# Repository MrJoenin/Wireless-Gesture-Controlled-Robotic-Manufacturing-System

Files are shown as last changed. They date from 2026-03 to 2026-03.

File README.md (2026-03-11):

# 🦾 Wireless Gesture-Controlled Robotic Manufacturing System

A 6-DOF robotic arm controlled wirelessly in real-time using hand gestures captured by an MPU6050 IMU and transmitted via RF communication.

---

## 📸 Demo
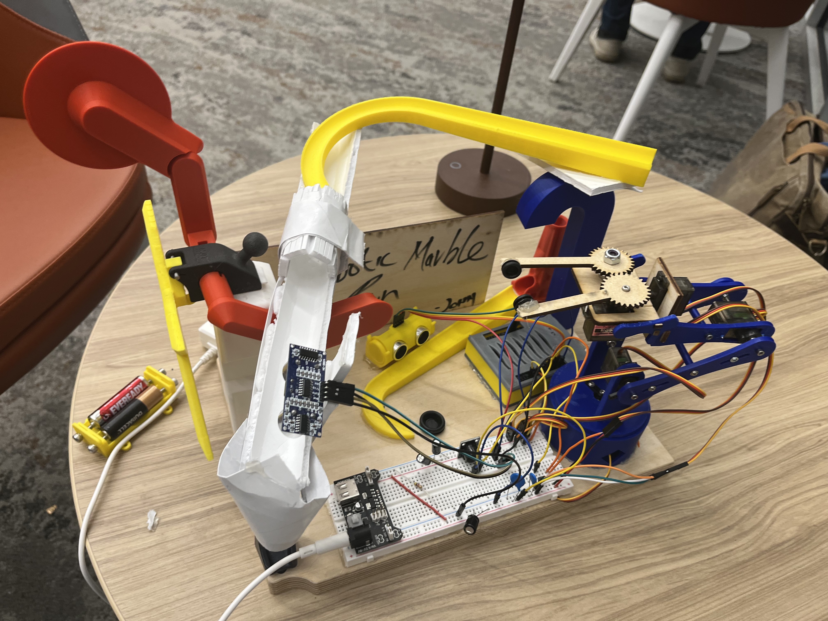
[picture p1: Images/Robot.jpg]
Wireless Gesture-Controlled Robotic Arm


🎥 [Watch Full Demo Video](https://drive.google.com/drive/folders/1Te0tW6EEjBbD6eXdm4avNDmqE-6lIaKK?usp=drive_link)

---

## 🔍 Overview

This system allows an operator to control a robotic arm simply by moving their hand. An **MPU6050 gyroscope/accelerometer** captures wrist orientation and transmits motion data wirelessly via **RF modules** to a receiver Arduino that drives **6 servo motors** — one per joint. An **ultrasonic sensor** detects nearby objects and triggers a **buzzer** as a proximity alert.

This project was built as a group capstone for **ECET-230-001**, covering embedded systems, wireless communication, PCB design, and mechanical design end-to-end.

---

## ✨ Features

- Real-time wireless gesture control via MPU6050 IMU (pitch, roll, yaw)
- 6 degrees of freedom — base, shoulder, elbow, wrist pitch, wrist roll, gripper
- RF 433MHz communication between handheld controller and arm
- Ultrasonic proximity detection with piezo buzzer audio alert
- LCD display for live system status feedback
- Custom PCB designed in KiCad
- 3D printed mechanical structure (PLA+ / PETG)
- Full project documentation: schematics, logs, test plans, CAD files

---

## ⚙️ Hardware Components

| Component | Quantity | Purpose |
|---|---|---|
| Arduino Uno | 2 | Transmitter & Receiver microcontrollers |
| MPU6050 IMU | 1 | Captures hand orientation (I2C) |
| RF Transmitter + Receiver (433MHz) | 1 pair | Wireless data link |
| Servo Motors | 6 | Drives each joint of the arm |
| Ultrasonic Sensor (HC-SR04) | 2 | Object/proximity detection |
| Piezo Buzzer | 1 | Audio proximity alert |
| LCD Display (I2C) | 1 | Live system status |
| Push Buttons | 5 | Manual input controls |
| LEDs (Red & Green) | 2 | Status indicators |
| 9V Battery + Battery Pack | 1 | Portable power supply |
| Custom PCB (KiCad) | 1 | Clean circuit integration |

**Estimated Total Cost: Under $150**

---

## 🧠 How It Works

```
[ Hand Movement ]
       ↓
[ MPU6050 reads pitch / roll / yaw ]
       ↓
[ Transmitter Arduino encodes data + sends via RF ]
       ↓
[ Receiver Arduino decodes signal ]
       ↓
[ 6 Servo motors move to matching joint angles ]
       ↓
[ Ultrasonic sensor monitors proximity → Buzzer alert ]
```

---

## 🛠️ Tools & Technologies

| Category | Tools |
|---|---|
| Programming | Arduino IDE (C/C++) |
| Mechanical Design | SolidWorks / Fusion 360 |
| PCB Design | KiCad |
| Manufacturing | 3D Printing (PLA+ / PETG), Laser Cutting |
| Version Control | GitHub |
| Libraries | `Wire.h`, `MPU6050.h`, `VirtualWire`, `Servo.h`, `LiquidCrystal_I2C.h` |

---

## 📁 Repository Structure

```
Wireless-Gesture-Controlled-Robotic-Manufacturing-System/
├── Software/           # Arduino .ino source files (transmitter & receiver)
├── Design/             # System architecture, block diagrams, circuit schematics
├── PCB Files/          # KiCad PCB design files
├── Robot 3D Model/     # SolidWorks / Fusion 360 CAD files
├── Logs/               # Weekly progress logs
├── Tasks/              # Task tracking and completion status
├── Definitions/        # Official project scope and requirements
├── Proof of Concept.md # Early validation and feasibility notes
├── Testing Document.md # Test cases, results, and validation
├── LICENSE
└── README.md
```

---

## 🚀 Getting Started

### Prerequisites
- Arduino IDE installed
- Required libraries (install via Library Manager):
  - `MPU6050` by Electronic Cats
  - `VirtualWire` or `RadioHead` for RF
  - `LiquidCrystal_I2C` for LCD
  - `Servo` (built-in)

### Upload Steps

1. Clone this repo:
   ```bash
   git clone https://github.com/MrJoenin/Wireless-Gesture-Controlled-Robotic-Manufacturing-System.git
   ```
2. Open `Software/transmitter.ino` → upload to the **controller Arduino** (with MPU6050)
3. Open `Software/receiver.ino` → upload to the **arm Arduino**
4. Power both units — the arm will mirror hand movements in real time

---

## 📆 Project Timeline

| Phase | Duration | Description |
|---|---|---|
| Research & Planning | Weeks 1–2 | Brainstorm, block diagram, parts research |
| Design & Prototyping | Weeks 3–6 | CAD models, circuit design, PCB layout |
| Implementation | Weeks 7–10 | Build prototype, write firmware |
| Testing & Debugging | Weeks 11–12 | Verify requirements, fix issues |
| Final Delivery | Week 13 | Report, presentation, live demo |

---

## 🧩 Challenges & What We Learned

- **Servo power management** — Powering all 6 servos from the Arduino caused brownouts. Fixed by using a dedicated external supply with a shared ground.
- **RF signal reliability** — Raw RF is noisy; added basic packet validation to prevent erratic servo movement from corrupted signals.
- **IMU drift** — Raw gyroscope data drifts over time. Applied a complementary filter combining accelerometer + gyroscope data for stable, accurate readings.
- **PCB design iteration** — First PCB revision had routing issues; KiCad's DRC tool helped catch and fix them before fabrication.

---

## 🔮 Future Improvements

- [ ] Upgrade to nRF24L01 for bidirectional, more reliable communication
- [ ] Add inverse kinematics for coordinate-based positioning
- [ ] Implement a mobile app as an alternative controller
- [ ] Add force feedback on the gripper
- [ ] Update Receiver and Transmitter PCB

---

## 👥 Team

| Member | Role |
|---|---|
| John (MrJoenin) | CAD, Mechanical Design |
| Alicia | Coding, Testing & Validation |
| Larbi | Research, Schematics, PCB Design |

---

## 📄 License

This project is open source under the [MIT License](LICENSE).  
Feel free to use and modify with attribution.

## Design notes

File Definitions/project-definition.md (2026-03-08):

# Project Definition

## Project Title
6DOF robot controlled by MPU6050

## Team Members
- John Yalley (role: CAD Model and Component selection)
- Alicia  (role: Coding and PCB Design)
- Larbi  (role: Research)

## Problem Statement
- Move marble from point A to B

## Objectives
- Build a functional robotic arm with 5 DOF
- Use Arduino for easy programming.
- Mpu6050 for robot control
- Wireless communication 

## Requirements
- Operate on 9V DC
- Controlled via or RF transmitter and Receiver
- Budget under $150.

## Component selection
- Servo x5
- MPU 6050 x1
- Arduino x2
- Wires
- LED x3
- LCD Display x1
- Push Buttons x2
- Ultrasonic Sensor x2
- Buzzer
- RF transmitter and receiver

## Constraints
- Limited time (one semester).
- Must use available 3D printing material (PLA+/PETG).
- Only off-the-shelf electronics allowed.
- RF Transmittter and Reciever
- Arduino Uno

## Deliverables
- Working robotic arm prototype.
- Documentation (design, logs, tasks, test results).
- Final presentation/demo.

## Timeline (Example)
- Weeks 1–2: Research and planning
- Weeks 3–5: Design and parts selection
- Weeks 6–8: Circuit and code development
- Weeks 9–11: Assembly and testing
- Week 12: Final presentation

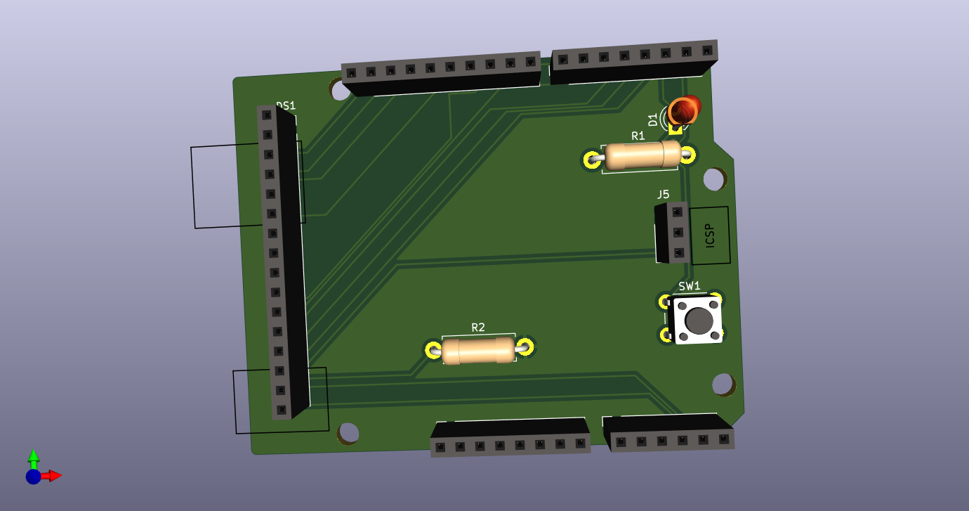
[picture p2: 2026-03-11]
PCB Files/robotv2/robotv2_transmitter/robotv2_transmitter.png

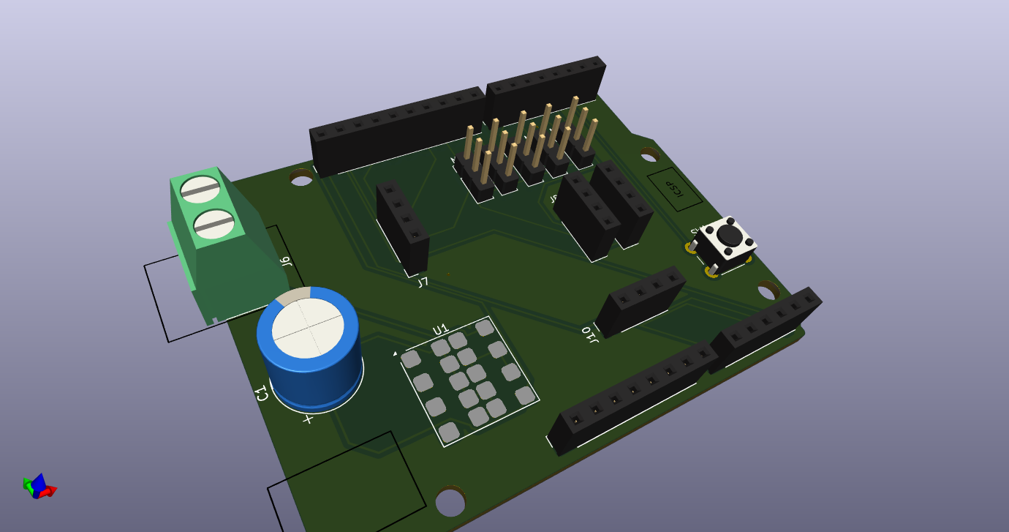
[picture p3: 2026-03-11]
PCB Files/robotv2/robotv2_reciever/robotv2_image.png

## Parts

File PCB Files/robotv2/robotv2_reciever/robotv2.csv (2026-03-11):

Id | Designator | Footprint | Quantity | Designation | Supplier and ref
1 | J10 | PinSocket_1x04_P2.54mm_Vertical | 1 | I2C Display
2 | J6 | TerminalBlock_Phoenix_MKDS-1,5-2-5.08_1x02_P5.08mm_Horizontal | 1 | battery
3 | SW1 | SW_PUSH_6mm | 1 | SW_Push
4 | J9 | PinSocket_1x04_P2.54mm_Vertical | 1 | Sensor2
5 | J8 | PinSocket_1x04_P2.54mm_Vertical | 1 | Sensor1
6 | J7 | PinSocket_1x04_P2.54mm_Vertical | 1 | RF Reciver
7 | C1 | CP_Radial_D10.0mm_P2.50mm | 1 | 1000uf
8 | U1 | MPS_LGA-18-10EP_12x12mm_P3.3mm | 1 | MPM3550EGLE
9 | M5,M4,M3,M1 | PinHeader_1x03_P2.54mm_Vertical | 4 | Base
10 | M2 | PinHeader_1x03_P2.54mm_Vertical | 1 | Shoulder
11 | J1 | PinSocket_1x08_P2.54mm_Vertical | 1 | Power
12 | J3 | PinSocket_1x06_P2.54mm_Vertical | 1 | Analog
13 | J2 | PinSocket_1x10_P2.54mm_Vertical | 1 | Digital/PWM
14 | J4 | PinSocket_1x08_P2.54mm_Vertical | 1 | Digital/PWM

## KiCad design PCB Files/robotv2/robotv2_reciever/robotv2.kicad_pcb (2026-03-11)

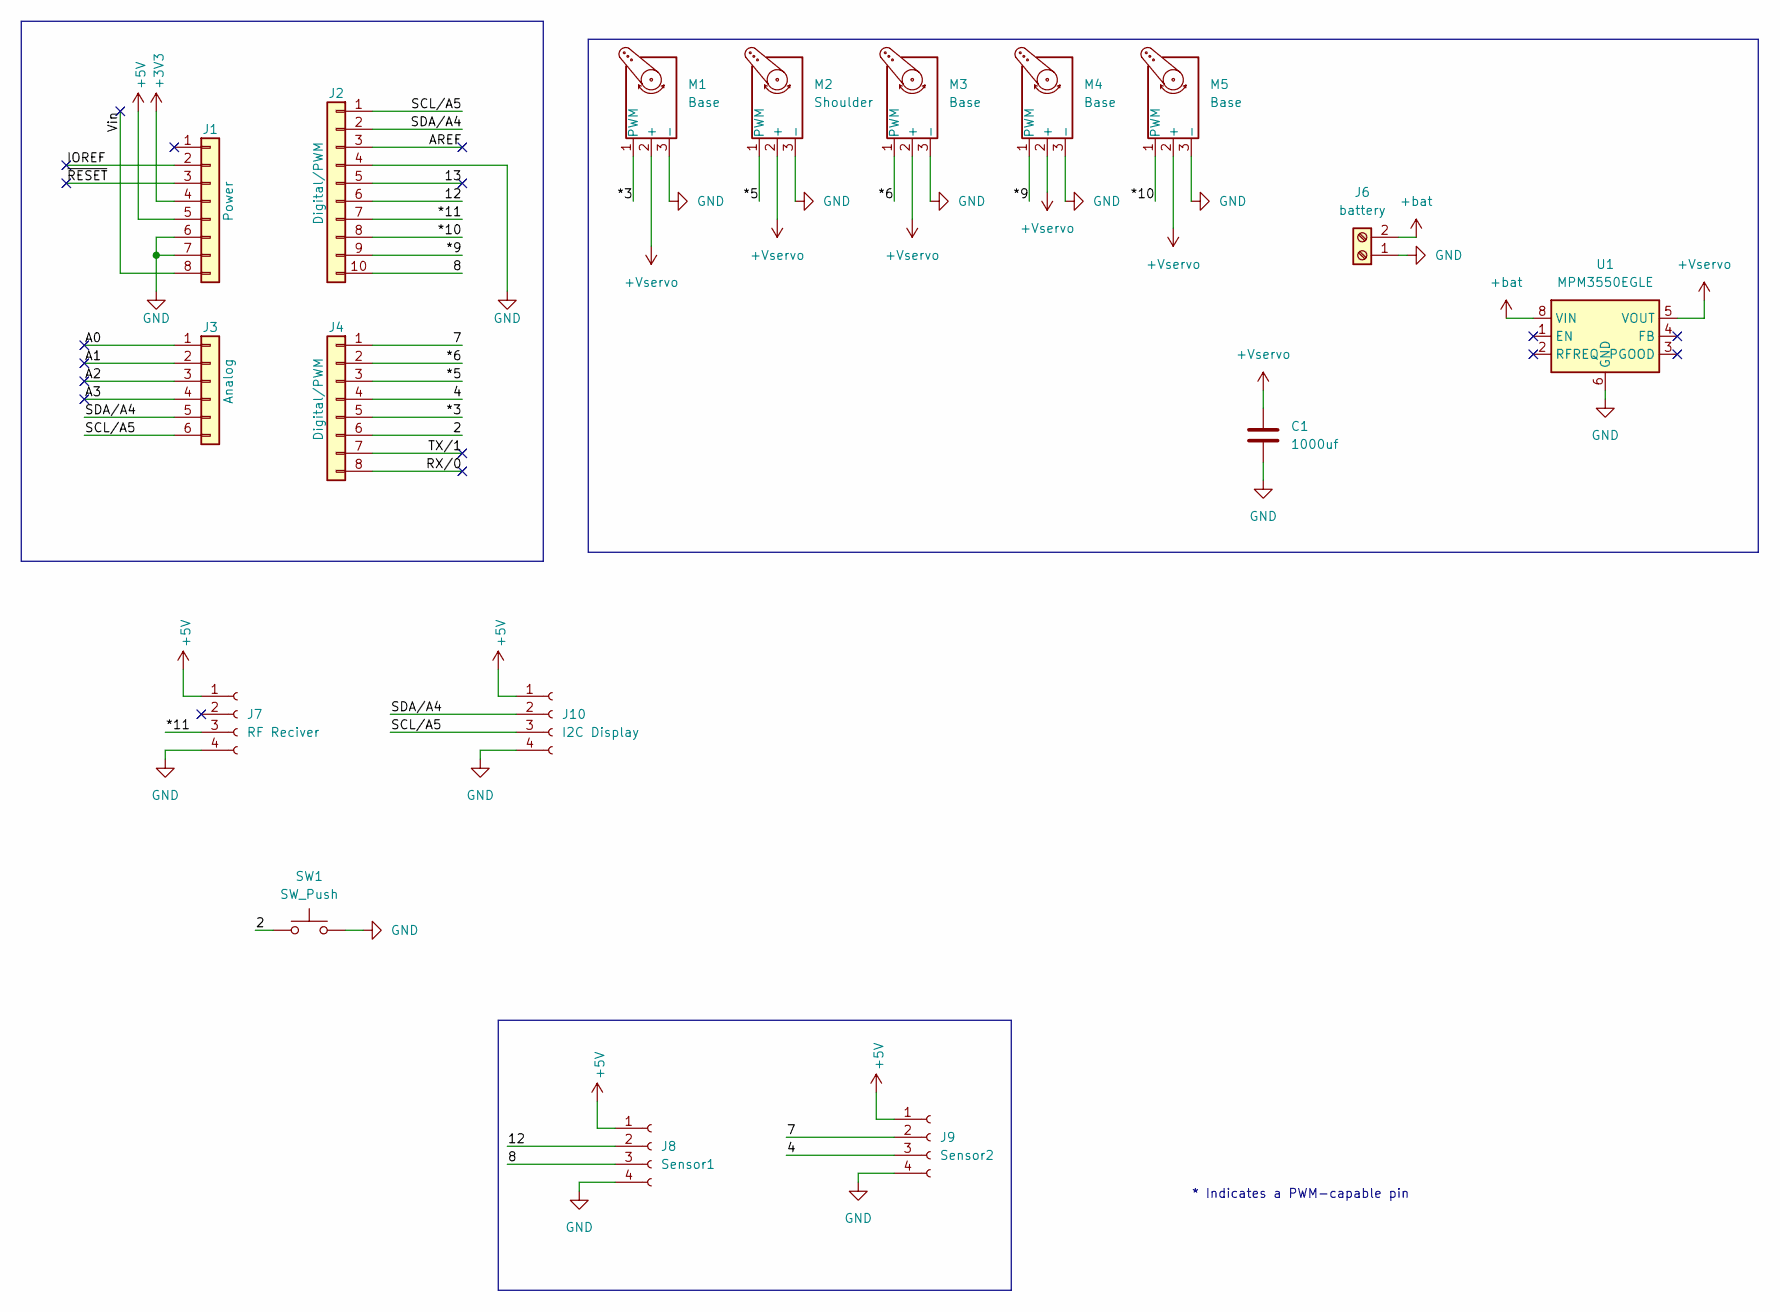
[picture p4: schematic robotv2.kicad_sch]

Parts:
C1: 1000uf; CP_Radial_D10.0mm_P2.50mm
J1: Power; PinSocket_1x08_P2.54mm_Vertical
J2: Digital/PWM; PinSocket_1x10_P2.54mm_Vertical
J3: Analog; PinSocket_1x06_P2.54mm_Vertical
J4: Digital/PWM; PinSocket_1x08_P2.54mm_Vertical
J6: battery; TerminalBlock_Phoenix_MKDS-1,5-2-5.08_1x02_P5.08mm_Horizont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
J7: RF Reciver; PinSocket_1x04_P2.54mm_Vertical
J8: Sensor1; PinSocket_1x04_P2.54mm_Vertical
J9: Sensor2; PinSocket_1x04_P2.54mm_Vertical
J10: I2C Display; PinSocket_1x04_P2.54mm_Vertical
M1, M3, M4, M5: Base; PinHeader_1x03_P2.54mm_Vertical
M2: Shoulder; PinHeader_1x03_P2.54mm_Vertical
SW1: SW_Push; SW_PUSH_6mm
U1: MPM3550EGLE; MPS_LGA-18-10EP_12x12mm_P3.3mm

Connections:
+3V3: J1.4
+5V: J1.5, J7.1, J8.1, J9.1, J10.1
+Vservo: C1.1, M1.2 (+), M2.2 (+), M3.2 (+), M4.2 (+), M5.2 (+), U1.5 (VOUT)
+bat: J6.2, U1.8 (VIN)
/2: J4.6, SW1.1
/4: J4.4, J9.3
/7: J4.1, J9.2
/8: J2.10, J8.3
/12: J2.6, J8.2
/13: J2.5
/*3: J4.5, M1.1 (PWM)
/*5: J4.3, M2.1 (PWM)
/*6: J4.2, M3.1 (PWM)
/*9: J2.9, M4.1 (PWM)
/*10: J2.8, M5.1 (PWM)
/*11: J2.7, J7.3
/A0: J3.1
/A1: J3.2
/A2: J3.3
/A3: J3.4
/AREF: J2.3
/IOREF: J1.2
/RX/0: J4.8
/SCL/A5: J2.1, J3.6, J10.3
/SDA/A4: J2.2, J3.5, J10.2
/TX/1: J4.7
/Vin: J1.8
/~RESET: J1.3
GND: C1.2, J1.6, J1.7, J2.4, J6.1, J7.4, J8.4, J9.4, J10.4, M1.3 (-), M2.3 (-), M3.3 (-), M4.3 (-), M5.3 (-), SW1.2, U1.6 (GND), U1.7 (GND), U1.9 (GND), U1.10 (GND), U1.11 (GND), U1.12 (GND), U1.13 (GND), U1.14 (GND), U1.15 (GND), U1.16 (GND), U1.17 (GND), U1.18 (GND)

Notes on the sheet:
* Indicates a PWM-capable pin

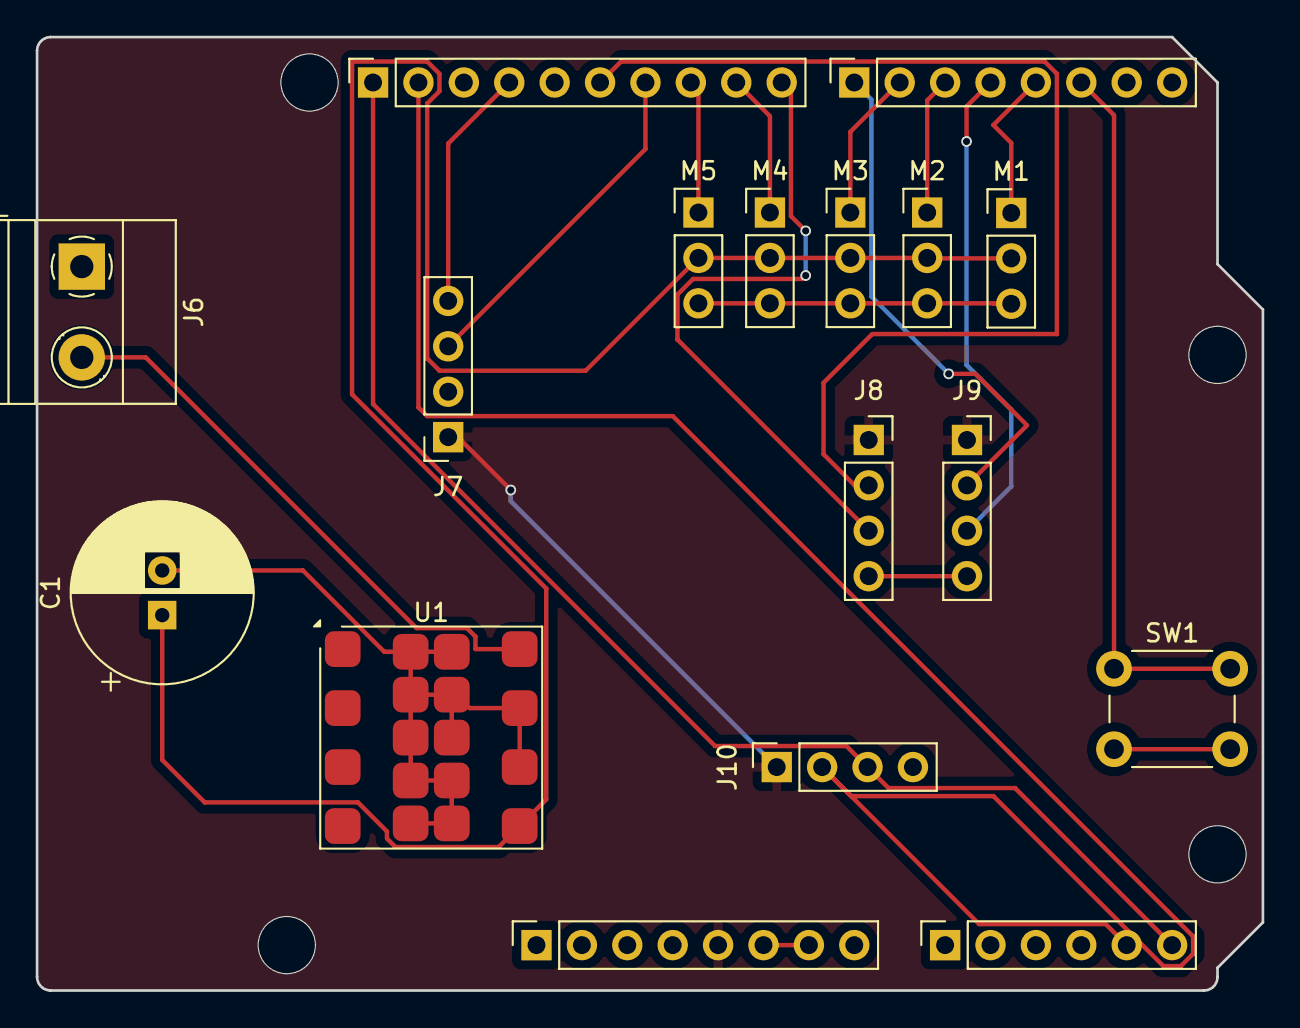
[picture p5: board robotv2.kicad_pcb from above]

Board: 2 copper layers, 68.6 x 53.3 mm, 21 parts (0 on the bottom side), 17 nets.

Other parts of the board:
MH1, MH2, MH3, MH4: MountingHole_3.2mm

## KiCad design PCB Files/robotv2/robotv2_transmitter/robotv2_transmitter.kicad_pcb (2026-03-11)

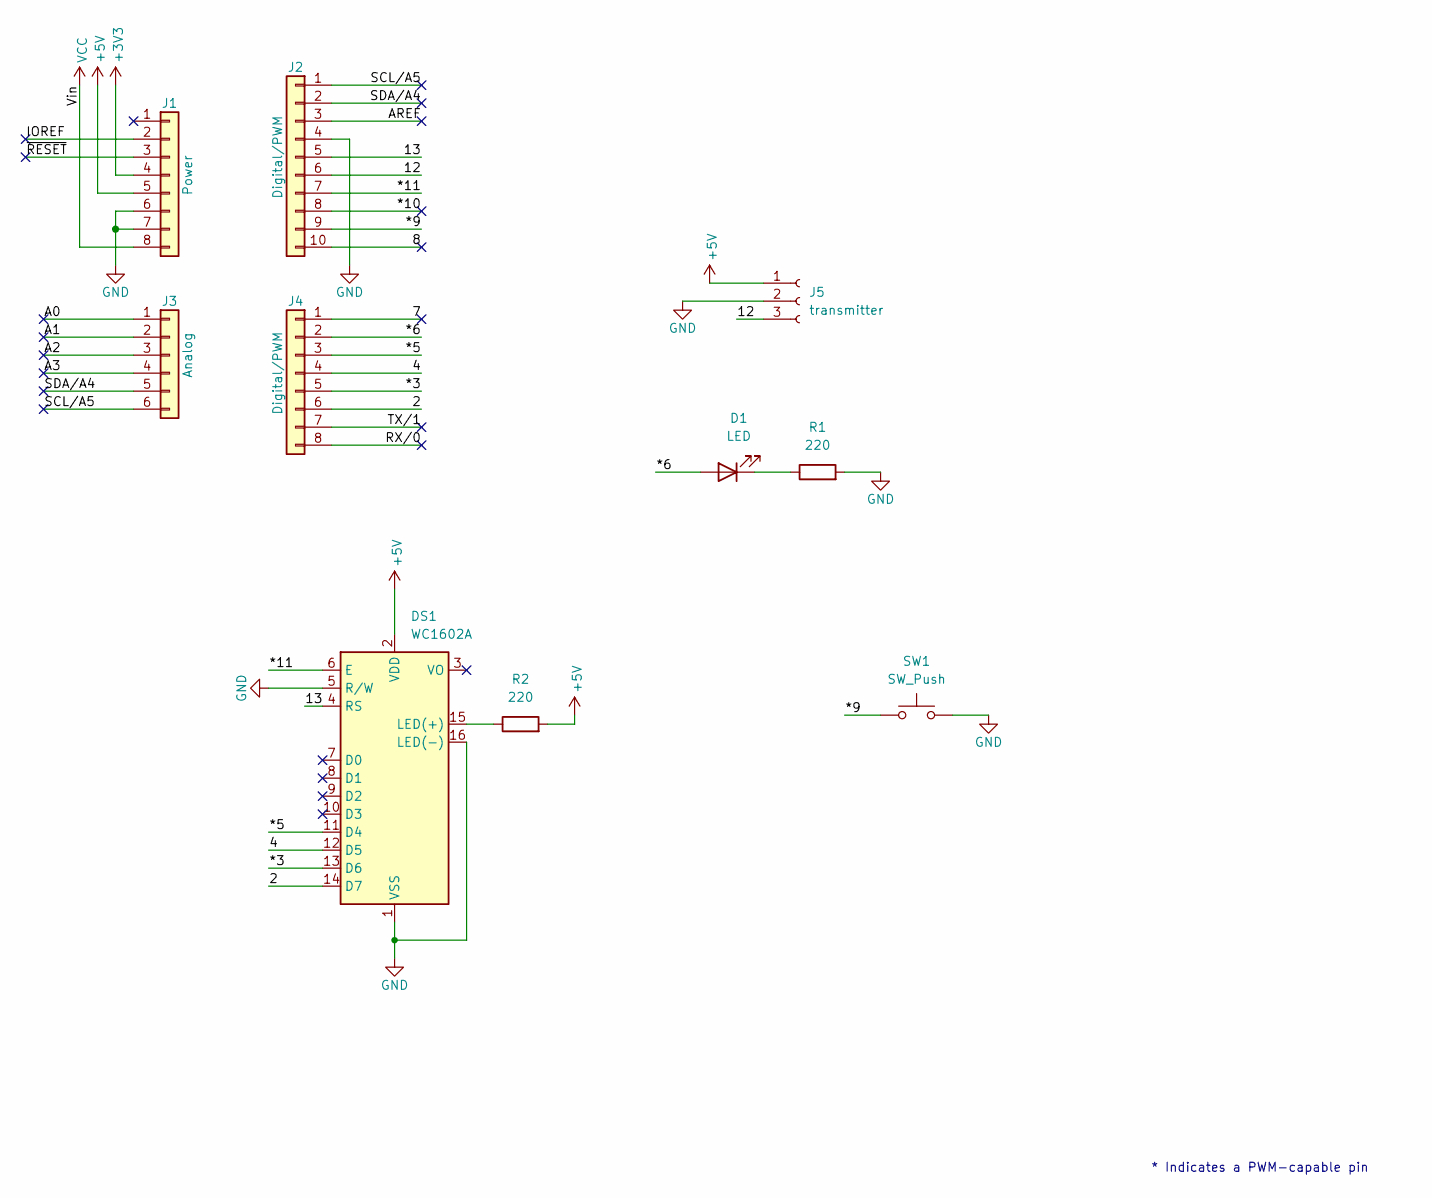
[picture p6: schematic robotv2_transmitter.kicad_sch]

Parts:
D1: LED; LED_D3.0mm
DS1: WC1602A; PinSocket_1x16_P2.54mm_Vertical
J1: Power; PinSocket_1x08_P2.54mm_Vertical
J2: Digital/PWM; PinSocket_1x10_P2.54mm_Vertical
J3: Analog; PinSocket_1x06_P2.54mm_Vertical
J4: Digital/PWM; PinSocket_1x08_P2.54mm_Vertical
J5: transmitter; PinSocket_1x03_P2.54mm_Vertical
R1, R2: 220; R_Axial_DIN0411_L9.9mm_D3.6mm_P12.70mm_Horizontal
SW1: SW_Push; SW_PUSH_6mm

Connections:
+3V3: J1.4
+5V: DS1.2 (VDD), J1.5, J5.1, R2.2
/2: DS1.14 (D7), J4.6
/4: DS1.12 (D5), J4.4
/7: J4.1
/8: J2.10
/12: J2.6, J5.3
/13: DS1.4 (RS), J2.5
/*3: DS1.13 (D6), J4.5
/*5: DS1.11 (D4), J4.3
/*6: D1.2 (A), J4.2
/*9: J2.9, SW1.1
/*10: J2.8
/*11: DS1.6 (E), J2.7
/A0: J3.1
/A1: J3.2
/A2: J3.3
/A3: J3.4
/AREF: J2.3
/IOREF: J1.2
/RX/0: J4.8
/SCL/A5: J2.1, J3.6
/SDA/A4: J2.2, J3.5
/TX/1: J4.7
/~RESET: J1.3
GND: DS1.1 (VSS), DS1.5 (R/W), DS1.16 (LED(-)), J1.6, J1.7, J2.4, J5.2, R1.2, SW1.2
unnamed: D1.1 (K), R1.1
unnamed: DS1.15 (LED(+)), R2.1
VCC: J1.8

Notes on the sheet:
* Indicates a PWM-capable pin

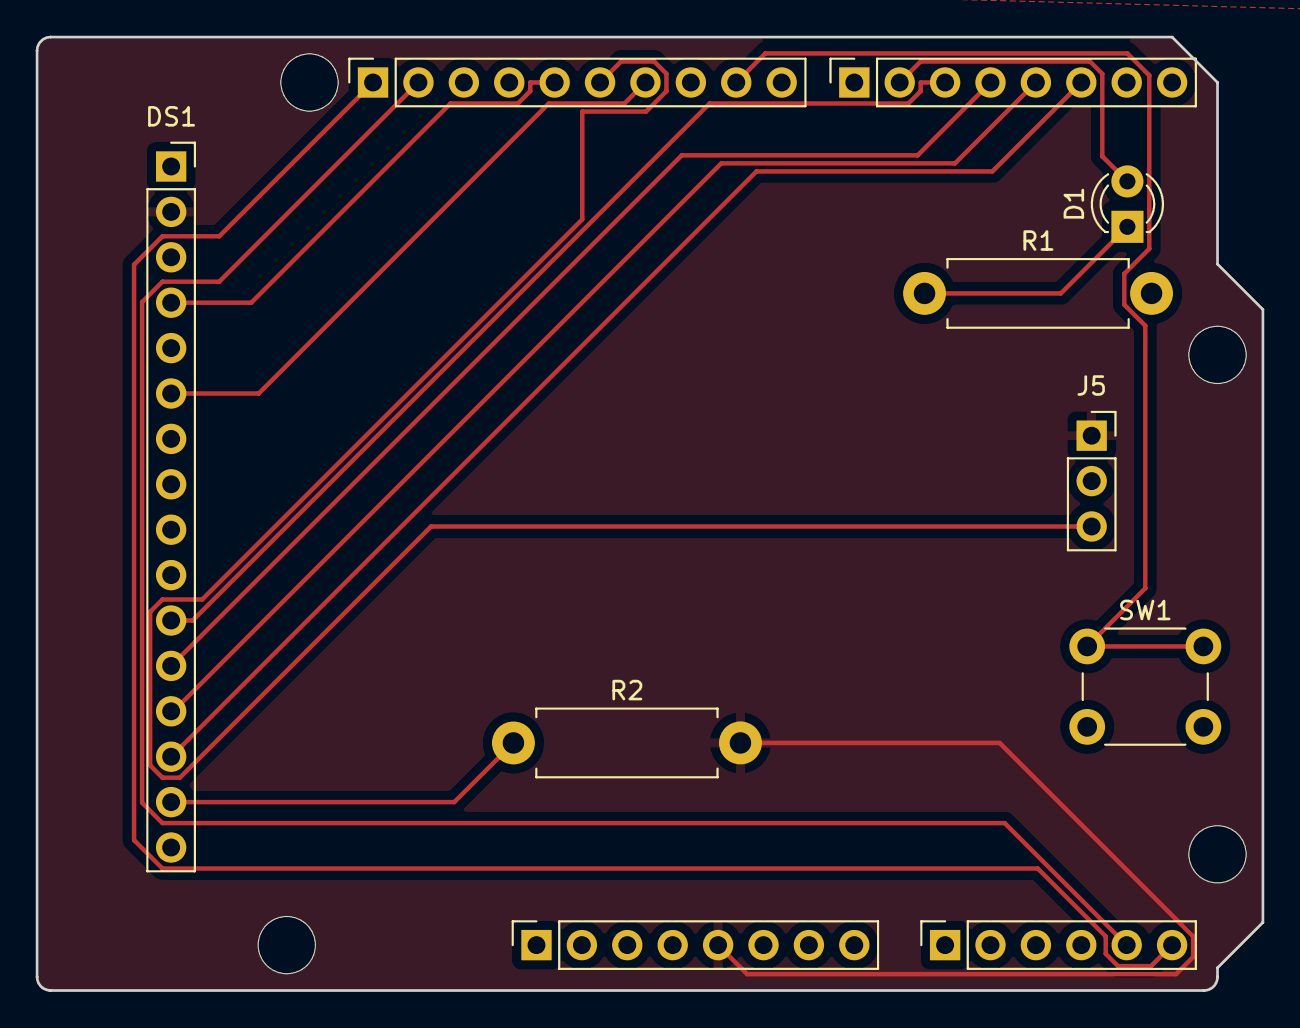
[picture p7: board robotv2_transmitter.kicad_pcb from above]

Board: 2 copper layers, 68.6 x 53.3 mm, 14 parts (0 on the bottom side), 15 nets.

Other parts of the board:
MH1, MH2, MH3, MH4: MountingHole_3.2mm

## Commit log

2026-03-08 Add demo image for robotic arm
    Added an image of the Wireless Gesture-Controlled Robotic Arm to the demo section.
2026-03-11 Fix typo in servo power management description
    Corrected a typo in the servo power management section of the README.
